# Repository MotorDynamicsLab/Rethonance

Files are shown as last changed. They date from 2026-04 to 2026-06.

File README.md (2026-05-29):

# Unicorn Chasing Kit

The Unicorn Chasing Kit is a resonance compensation toolkit centred around two core components: the Rethonance Nozzle, a V6-compatible nozzle with a built-in ADXL345 accelerometer and the Rethonance Hub, a magnetic, bed-mountable board that consolidates connectivity for ADXL sensors, motor thermistors, and a GPIO expansion port — all over a single USB connection. Together, they provide a convenient way for users to precisely measure resonance at where it actually matters - the nozzle.

## Rethonance Nozzle

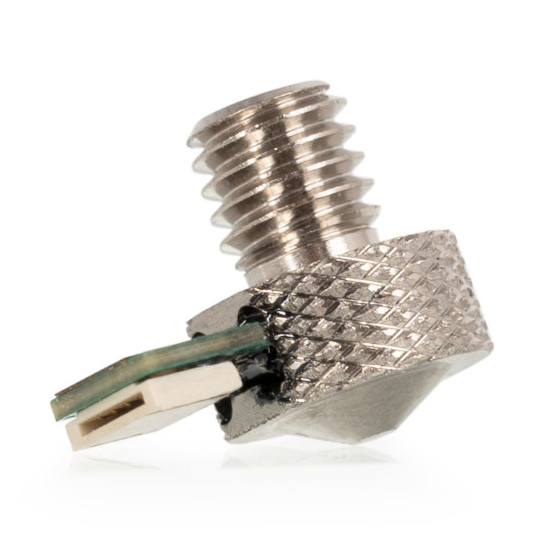
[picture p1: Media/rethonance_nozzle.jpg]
rethonance-nozzle
  

The Rethonance Nozzle was designed by Cyd0nian and Reth as one of the only known true nozzle-integrated ADXL solutions available (alongside the E3D Revo Rethonance Nozzle). The concept is straightforward: rather than relying on a separate ADXL board, the sensor is embedded directly into the nozzle itself. Developed in collaboration with LDO, the Rethonance Nozzle serves as the foundation of The *Unicorn Chasing Club*.

The Rethonance Nozzle is a V6-style nozzle with a built-in ADXL345 accelerometer, featuring a non-ZIF (press-in) FFC connector. A thermistor is integrated into the nozzle which, in conjunction with the recommended Klipper configuration, protects the ADXL chip from overheating. The nozzle is compatible with any hotend that accepts V6-style nozzles.  

## Rethonance Hub

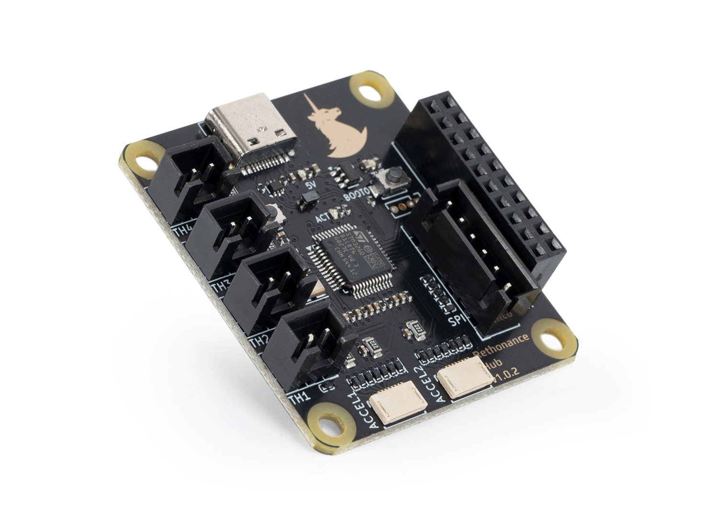
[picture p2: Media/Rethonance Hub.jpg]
rethonance-hub


The Rethonance Hub was developed to address a common inconvenience: the need to physically reposition a printer in order to connect an ADXL board. The solution is a dedicated board with a long USB cable and a magnetic mount, allowing it to be attached directly to the print bed for easy access.  

The Rethonance Hub features two press-in FFC connectors, both pin-compatible with either the LDO Rethonance Nozzle or E3D Revo Rethonance Nozzle. Additional features include four thermistor inputs — useful for monitoring motor temperatures on high-end AWD setups — as well as a third SPI port and a GPIO header for expanded connectivity and customization.

## Kit Contents

- Rethonance Nozzle
- Rethonance Hub
- 1.5m USB A to USB C cable
- 0.4m FFC Cable
- 6x3mm Magnets x3

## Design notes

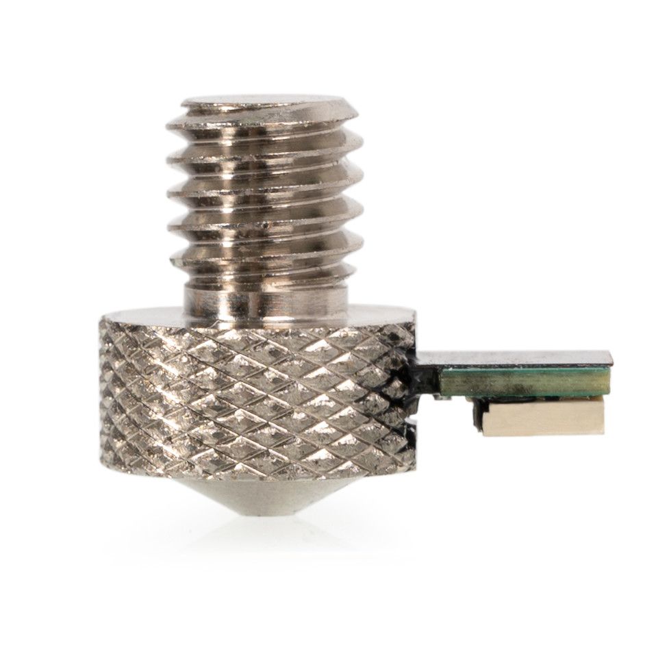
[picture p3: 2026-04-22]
Media/rethonance_nozzle_1.jpg

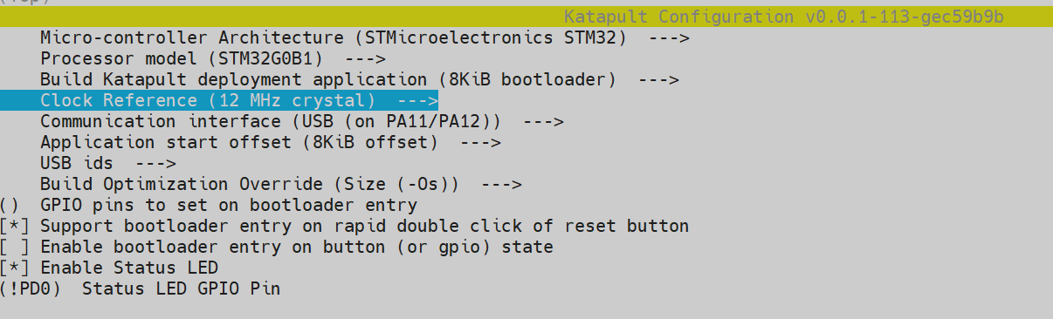
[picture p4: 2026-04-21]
Media/katapult_menuconfig.png

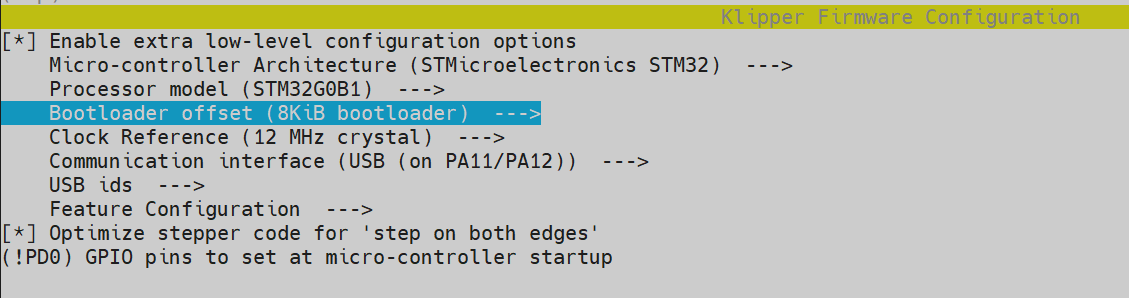
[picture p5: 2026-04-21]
Media/klipper_menuconfig.png

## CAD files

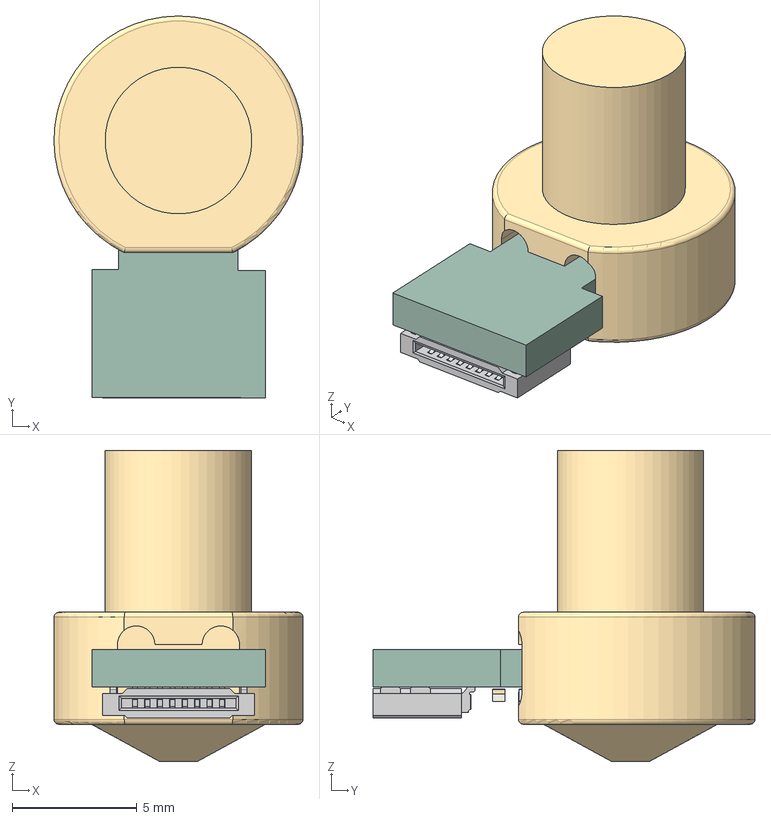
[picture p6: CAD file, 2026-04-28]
CAD/Rethonance Nozzle.step
10.00 x 15.3 x 12.5 mm
Round Nozzle
C_0402_1005Metric x 3
LGA-14_3x5mm_P0.8mm_LayoutBorder1x6y
R_0402_1005Metric
LED_0402_1005Metric
unicorn-accelerometer_PCB
unicorn-accelerometer 1.6.1

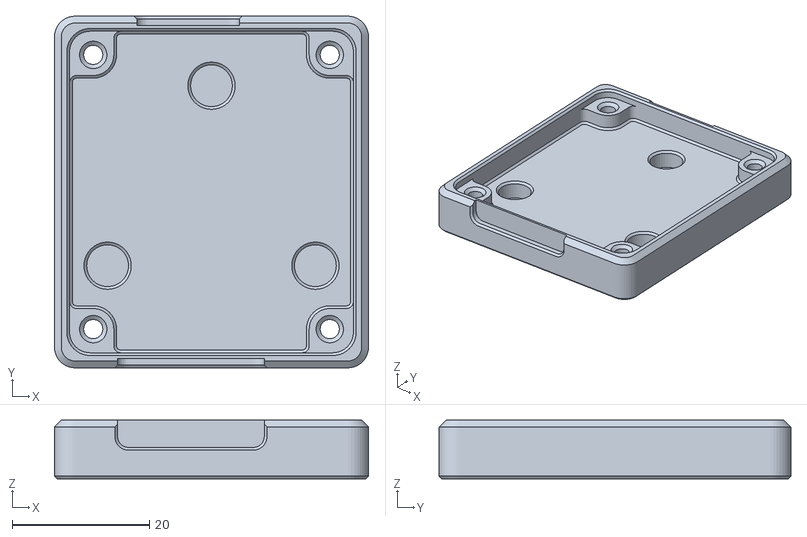
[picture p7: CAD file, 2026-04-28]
STLs/hub_mount.stl
45.8 x 51.3 x 8.60

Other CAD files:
STLs/Hub Mount.f3d

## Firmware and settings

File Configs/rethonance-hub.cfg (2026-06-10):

# This file contains pin mappings for the LDO Rethonance Hub

# See http://docs.ldomotors.com/toolboard/rethonance#firmware-setup-and-update
# For instructions on uploading/updating klipper firmware to the onboard mcu

# Klipper make menuconfig options:
# Processor model: STM32G0B1
# Bootloader offset (for Katapult): 8KiB bootloader
# Clock Reference: 12Mhz crystal
# Communication interface: USB (on PA11/PA12)

[mcu rth]
##  Obtain definition by "ls -l /dev/serial/by-id/" then unplug to verify
##--------------------------------------------------------------------
serial:/dev/serial/by-path/usb-Klipper_STM32_E012345678900000-if00
restart_method: command
##--------------------------------------------------------------------

[temperature_sensor rth]
sensor_type:temperature_host
max_temp:80

#####################################################################
#   ADXL Thermister Definition
#####################################################################
[thermistor NCU15WF104D60RC]
temperature1: 25
resistance1: 100000
beta: 4250

#####################################################################
#   Accelerometer Port 1
#####################################################################
# [adxl345 accel1]
# cs_pin: rth:PA1
# spi_bus: spi1_PA6_PA7_PA5
  
# [temperature_sensor accel1_th]
# sensor_type: NCU15WF104D60RC
# sensor_pin: rth:PB0
# pullup_resistor: 2200
# min_temp: 0
# max_temp: 35 #keep temperature low as heat from nozzle will take time to reach adxl345

#####################################################################
#   Accelerometer Port 2
#####################################################################
# [adxl345 accel2]
# cs_pin: rth:PB13
# spi_bus: spi2_PB2_PB11_PB10

# [temperature_sensor accel2_th]
# sensor_type: NCU15WF104D60RC
# sensor_pin: rth:PB12
# pullup_resistor: 2200
# min_temp: 0
# max_temp: 35 #keep temperature low as heat from nozzle will take time to reach adxl345

#####################################################################
#   Thermistor Ports
#####################################################################
# [temperature_sensor rth_th1]
# sensor_type: <Add your thermister here>
# sensor_pin: rth:PA4
# pullup_resistor: 2200
# min_temp: 0
# max_temp: 200

# [temperature_sensor rth_th2]
# sensor_type: <Add your thermister here>
# sensor_pin: rth:PA0
# pullup_resistor: 2200
# min_temp: 0
# max_temp: 200

# [temperature_sensor rth_th3]
# sensor_type: <Add your thermister here>
# sensor_pin: rth:PA2
# pullup_resistor: 2200
# min_temp: 0
# max_temp: 200
 
# [temperature_sensor rth_th4]
# sensor_type: <Add your thermister here>
# sensor_pin: rth:PA3
# pullup_resistor: 2200
# min_temp: 0
# max_temp: 200

#####################################################################
#   SPI Port - add any other SPI device
#####################################################################
# [adxl345 another_spi_device]
# cs_pin: rth:PA6
# spi_software_sclk_pin: rth:PB3
# spi_software_mosi_pin: rth:PB5
# spi_software_miso_pin: rth:PB4

#####################################################################
#   GPIO Port
#####################################################################
#GPIO pin - free GPIO pins. Share what you do with them
# 5V               GND
# 3.3V             GND
# unicorn:PB8      unicorn:PB9
# unicorn:PD1      unicorn:PB7
# unicorn:PD3      unicorn:PD2
# unicorn:PC14     unicorn:PC13
# <not used>       unicorn:PC15
# unicorn:PC7      unicorn:PA10
# unicorn:PA9      unicorn:PC6
# unicorn:PB15     unicorn:PA8

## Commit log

2026-04-15 add initial config file and placeholder README.md
    [rethonance-hub.cfg]
2026-04-15 Update rethonance-hub.cfg
    Changed the config around a bit and added GPIO ports
    [rethonance-hub.cfg]
2026-04-15 fix syntax errors in config
    [rethonance-hub.cfg]
2026-04-20 add printed mount for hub board
    [Hub Mount.f3d, hub_mount.stl]
2026-04-22 add photos of rethonance nozzle
2026-04-22 crop rethonance nozzle images
2026-04-27 Update rethonance-hub.cfg
    reduced adxl345 temp in config to make sure accidental nozzle heating doesn't ruin adxl345
    [rethonance-hub.cfg]
2026-04-28 minor update to hub mount
    [Hub Mount.f3d, hub_mount.stl]
2026-04-28 added 3D models for nozzle and hub
    [Rethonance Nozzle.step]
2026-06-10 update config
    [rethonance-hub.cfg]
